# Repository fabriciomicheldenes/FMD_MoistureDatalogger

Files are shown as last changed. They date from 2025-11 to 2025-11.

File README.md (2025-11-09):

# 🌱 Datalogger de Umidade do Solo *FMD_Soil Moisture*

## 📘 Visão Geral

 O **FMD_Soil Moisture** é um sistema autônomo para **monitoramento contínuo de umidade e temperatura do solo**, com armazenamento local e conectividade Wi-Fi e Serial-USB.

Projetado para aplicações agrícolas e experimentais, o sistema registra dados ambientais em longo prazo com alta confiabilidade e baixo custo.

O projeto é baseado em um **Arduino Mega 2560**, que coleta leituras de múltiplos sensores capacitivos de umidade do solo **HW-101 HW**, além de um sensor **DHT22** para temperatura e umidade do ar.

Os dados são registrados em **cartão microSD** e podem ser sincronizados via **módulo ESP-01 (ESP8266)** para monitoramento remoto.

## 🧩 Hardware - Arquitetura Geral

### 🔹 Componentes Principais

| Módulo / Componente | Função | Interface | Observações |
| --- | --- | --- | --- |
| **Arduino Mega 2560** | Unidade de controle principal | – | 16 canais analógicos nativos + expansão SPI |
| **Sensores de Umidade Capacitivos (HW-101 HW V1.2 / V2.0)** | Medição de umidade do solo | Analógica (0–5 V) | 16 sensores diretos + 2 via MCP3008 |
| **MCP3008** | Conversor A/D externo de 8 canais | SPI | Expande entradas |
| **DHT22** | Temperatura e umidade do ar | 1 fio (digital) | Sensor ambiente |
| **ESP-01 (ESP8266)** | Comunicação Wi-Fi | UART | Upload de dados ou configuração remota |
| **RTC DS1307 + Bateria 3 V** | Relógio e calendário | I²C | Mantém data/hora durante desligamento |
| **MicroSD Card (SPI)** | Armazenamento local | SPI | Indicadores de status via LEDs |
| **LEDs de Status (3×)** | Indicação do estado do SDCard | GPIO | - Sem cartão<br>- Falha no cartão<br>- Cartão OK (pisca ao gravar) |

## ⚙️ Recursos Adicionais (não implementados (no firmware) na versão atual)

| Recurso | Componente | Interface | Estado |
| --- | --- | --- | --- |
| Memória EEPROM externa | 24C32WP | I²C | Reservado |
| Display LCD 1602 | HD44780 (modo 4 bits) | GPIO | Reservado |
| Display 5110 | Nokia 5110 | SPI | Reservado |
| Teclado | Teclado matricial 4×4 | GPIO | Reservado |
| Expansão ADC | MCP3008 (canais livres) | SPI | Reservado |

## 🔌 Conectores de Expansão

| Conector | Interface | Descrição |
| --- | --- | --- |
| **Expansão A** | I²C, 1× I/O, 2× PWM | Compatível com sensores e atuadores externos |
| **Expansão B** | SPI, CS, 1× I/O, 1× PWM | Para módulos SPI adicionais |
| **Expansão C** | SPI, CS, 1× I/O, 1× PWM | Similar à Expansão B |
| **Expansão D (Serial)** | TX/RX, 1× I/O, 2× PWM | Conexão de módulos seriais ou periféricos externos |
| **Planejado** | RS-232 e RS-485 | UART + controle de hardware |

## 🧾 Histórico de Versões do Hardware

| Versão | Plataforma | Descrição | Status |
| --- | --- | --- | --- |
| **V0.1** | Proteus (ISIS + ARES) | Primeira versão funcional do circuito e layout | ✅ Testada |
| **V0.2** | KiCad 8 | Novo layout, roteamento otimizado e serigrafia revisada | 🔄 Atual  |

A **versão V0.1**, desenvolvida no *Proteus (ISIS + ARES)*, foi a primeira versão funcional do hardware, mas apresentava algumas limitações de projeto, como trilhas longas e cruzadas, componentes em ambos os lados e uso reduzido de plano de terra, exigindo pequenas correções com jumpers.

A **versão V0.2**, redesenhada no *KiCad 8*, manteve o mesmo circuito eletrônico, mas trouxe um layout mais maduro e eficiente: todos os componentes estão em um único lado, as trilhas são curtas e bem distribuídas, e há ampla costura de planos de terra em ambas as faces, resultando em **melhor imunidade a ruídos** e maior confiabilidade do sistema.

## 💾 Firmware

O firmware foi desenvolvido em **Arduino C++**, com foco em modularidade e confiabilidade para operação contínua.  
Ele realiza:

- Leitura sequencial dos sensores de umidade e do DHT22  
- Registro no **RTC DS1307** para carimbo de data/hora  
- Armazenamento no **microSD (FAT32)**  
- Indicação visual do status via LEDs  
- Envio de dados via **Wi-Fi (ESP-01)**  

### 🔹 Bibliotecas utilizadas

- `DHT.h` – leitura de temperatura/umidade  
- `Wire.h` – comunicação I²C (RTC e EEPROM)  
- `SPI.h` – comunicação SPI (SD e MCP3008)  
- `SD.h` – gerenciamento do cartão microSD  
- `SoftwareSerial.h` – interface serial com ESP-01  

> 🔗 Detalhes do código e pinagem em [`Firmware/README.md`](Firmware/README.md)

---

## 💻 Software de Visualização

O software de visualização foi desenvolvido em **Python/Qt**, permitindo:

- Leitura direta dos arquivos `.CSV` ou `.TXT` do microSD  
- Exibição de gráficos de tendência (umidade x tempo)  
- Exportação dos dados para análise estatística  
- Modo de operação **offline (SD)** e **online (Wi-Fi)**  

> 🔗 Documentação completa em [`Software/README.md`](Software/README.md)

---

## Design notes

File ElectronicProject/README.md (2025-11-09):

# 🌱 Datalogger de Umidade do Solo *FMD_Soil Moisture* – Hardware

## 📘 Visão Geral

 O **FMD_Soil Moisture** é um sistema autônomo para **monitoramento contínuo de umidade e temperatura do solo**, com armazenamento local e conectividade Wi-Fi e Serial-USB.

Projetado para aplicações agrícolas e experimentais, o sistema registra dados ambientais em longo prazo com alta confiabilidade e baixo custo.

O projeto é baseado em um **Arduino Mega 2560**, que coleta leituras de múltiplos sensores capacitivos de umidade do solo **HW-101 HW**, além de um sensor **DHT22** para temperatura e umidade do ar.

Os dados são registrados em **cartão microSD** e podem ser sincronizados via **módulo ESP-01 (ESP8266)** para monitoramento remoto.

## 🧩 Arquitetura Geral

### 🔹 Componentes Principais

| Módulo / Componente | Função | Interface | Observações |
| --- | --- | --- | --- |
| **Arduino Mega 2560** | Unidade de controle principal | – | 16 canais analógicos nativos + expansão SPI |
| **Sensores de Umidade Capacitivos (HW-101 HW V1.2 / V2.0)** | Medição de umidade do solo | Analógica (0–5 V) | 16 sensores diretos + 2 via MCP3008 |
| **MCP3008** | Conversor A/D externo de 8 canais | SPI | Expande entradas |
| **DHT22** | Temperatura e umidade do ar | 1 fio (digital) | Sensor ambiente |
| **ESP-01 (ESP8266)** | Comunicação Wi-Fi | UART | Upload de dados ou configuração remota |
| **RTC DS1307 + Bateria 3 V** | Relógio e calendário | I²C | Mantém data/hora durante desligamento |
| **MicroSD Card (SPI)** | Armazenamento local | SPI | Indicadores de status via LEDs |
| **LEDs de Status (3×)** | Indicação do estado do SDCard | GPIO | - Sem cartão<br>- Falha no cartão<br>- Cartão OK (pisca ao gravar) |

## ⚙️ Recursos Adicionais (não implementados (no firmware) na versão atual)

| Recurso | Componente | Interface | Estado |
| --- | --- | --- | --- |
| Memória EEPROM externa | 24C32WP | I²C | Reservado |
| Display LCD 1602 | HD44780 (modo 4 bits) | GPIO | Reservado |
| Display 5110 | Nokia 5110 | SPI | Reservado |
| Teclado | Teclado matricial 4×4 | GPIO | Reservado |
| Expansão ADC | MCP3008 (canais livres) | SPI | Reservado |

## 🔌 Conectores de Expansão

| Conector | Interface | Descrição |
| --- | --- | --- |
| **Expansão A** | I²C, 1× I/O, 2× PWM | Compatível com sensores e atuadores externos |
| **Expansão B** | SPI, CS, 1× I/O, 1× PWM | Para módulos SPI adicionais |
| **Expansão C** | SPI, CS, 1× I/O, 1× PWM | Similar à Expansão B |
| **Expansão D (Serial)** | TX/RX, 1× I/O, 2× PWM | Conexão de módulos seriais ou periféricos externos |
| **Planejado** | RS-232 e RS-485 | UART + controle de hardware |

## 🧾 Histórico de Versões do Hardware

| Versão | Plataforma | Descrição | Status |
| --- | --- | --- | --- |
| **V0.1** | Proteus (ISIS + ARES) | Primeira versão funcional do circuito e layout | ✅ Testada |
| **V0.2** | KiCad 8 | Novo layout, roteamento otimizado e serigrafia revisada | 🔄 Atual  |

As **Figuras 1 e 2** apresentam a **versão V0.1** da placa, elaborada utilizando o *Proteus* (ISIS + ARES).  
Embora plenamente funcional, essa versão apresentou algumas limitações construtivas, como **trilhas incompletas que precisaram ser interligadas externamente por jumpers**, um **layout ainda imaturo** com **componentes montados em ambos os lados da placa** e **trilhas longas que se cruzam**, resultando em **pouca área disponível para o plano de terra**.  
Esses aspectos podem ser observados nas **Figuras 3 e 4**, que mostram os lados **superior** e **inferior** da placa.

<figure>
  <p align="center">
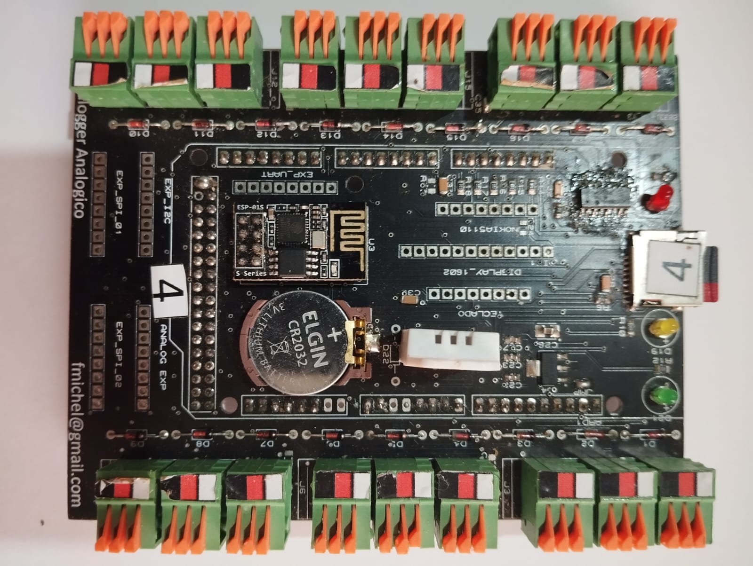
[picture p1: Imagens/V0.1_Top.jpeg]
Figura 1 – Placa V0.1 vista de cima
    
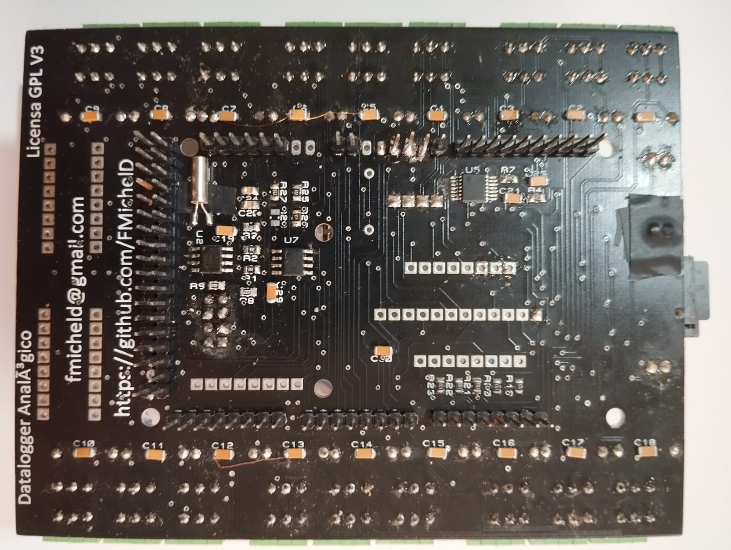
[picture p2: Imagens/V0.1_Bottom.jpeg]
Figura 2 – Placa V0.1 vista de baixo
    
  </p>
  <figcaption align="center"><b>Figura 1</b>: Placa V0.1 vista de cima.  <b> Figura 2</b>: – Placa V0.1 vista de baixo.</figcaption>
</figure>

<figure>
  <p align="center">
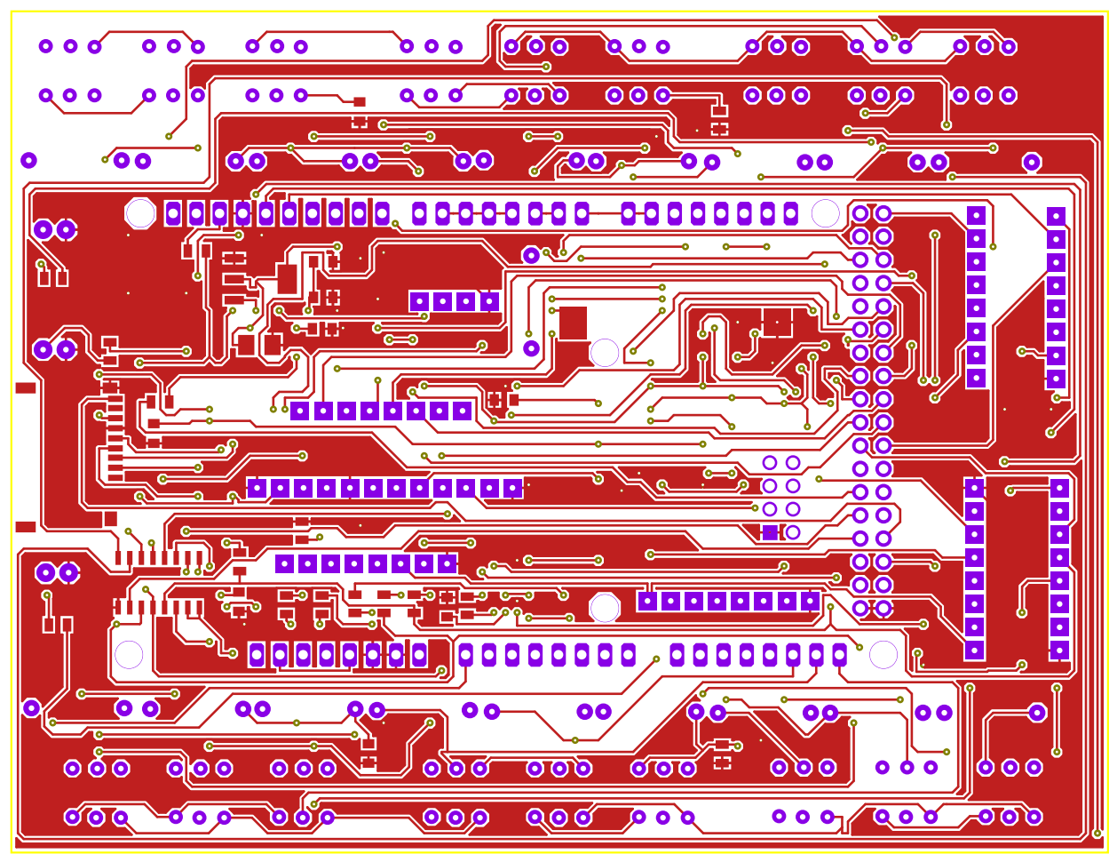
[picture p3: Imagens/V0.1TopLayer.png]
Figura 3 – Placa V0.1 Top layer
    
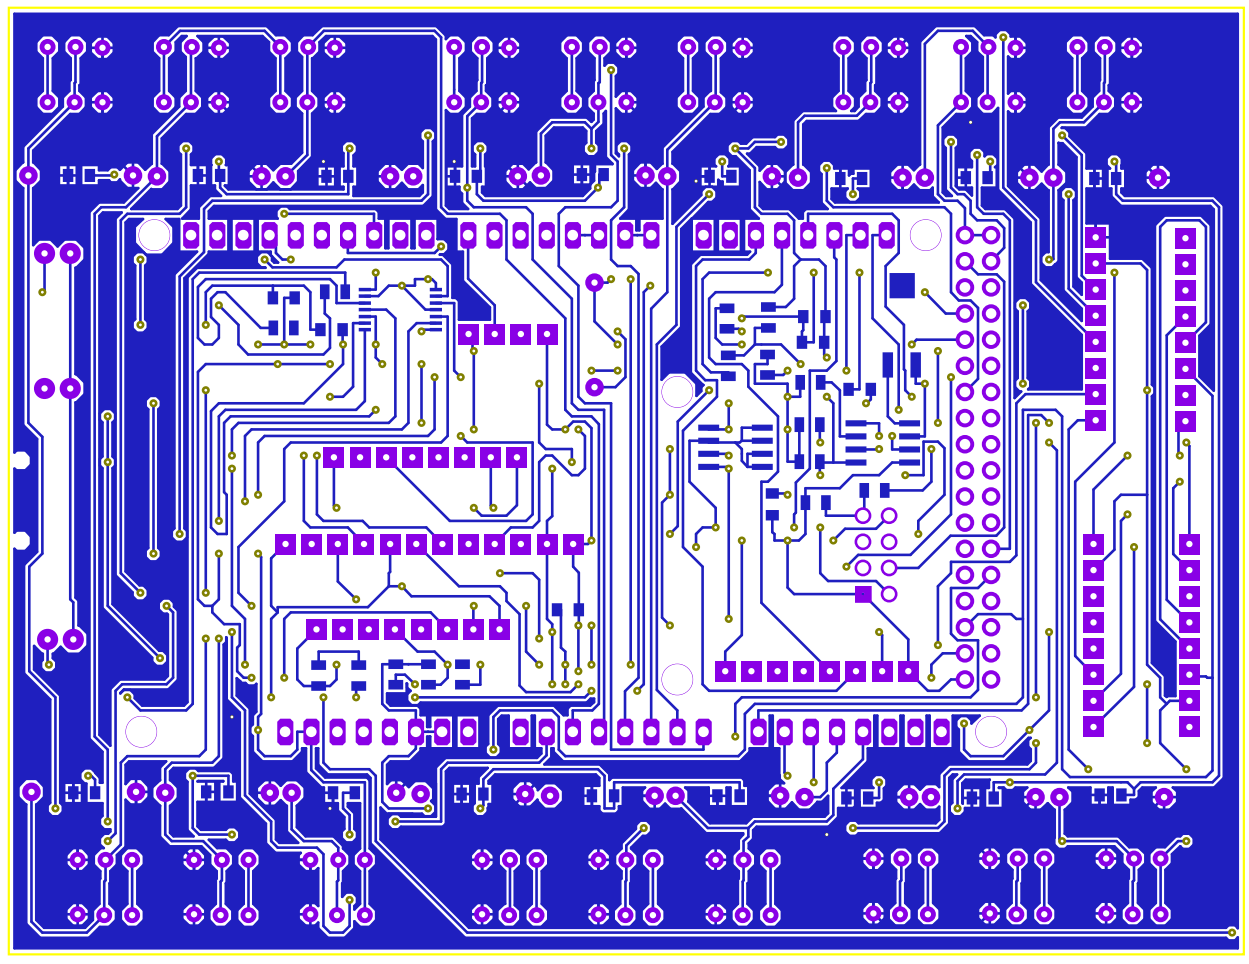
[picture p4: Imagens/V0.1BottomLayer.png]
Figura 4 – Bottom layer
    
  </p>
  <figcaption align="center"><b>Figura 3</b>: Placa V0.1 Top layer.  <b> Figura 4</b>: – Placa V0.1 Bottom layer.</figcaption>
</figure>>

A **versão V0.2**, desenvolvida no **KiCad**, manteve o mesmo circuito eletrônico da versão anterior, porém recebeu um **layout totalmente refeito**, com foco em otimização e robustez.  
Como ilustrado nas **Figuras 5 e 6**, o novo modelo 3D demonstra um **posicionamento mais racional dos componentes**, concentrados **em um único lado da placa**, com **trilhas mais curtas e diretas** e **ampla área para planos de terra em ambas as faces**.  
As **Figuras 7 e 8** evidenciam também a **costura entre planos de terra**, que contribui para **melhorar a imunidade a ruídos** e **reduzir interferências eletromagnéticas (EMI)**, tornando o hardware mais confiável para uso em ambientes agrícolas sujeitos a variações de umidade e ruído elétrico.

<figure>
  <p align="center">
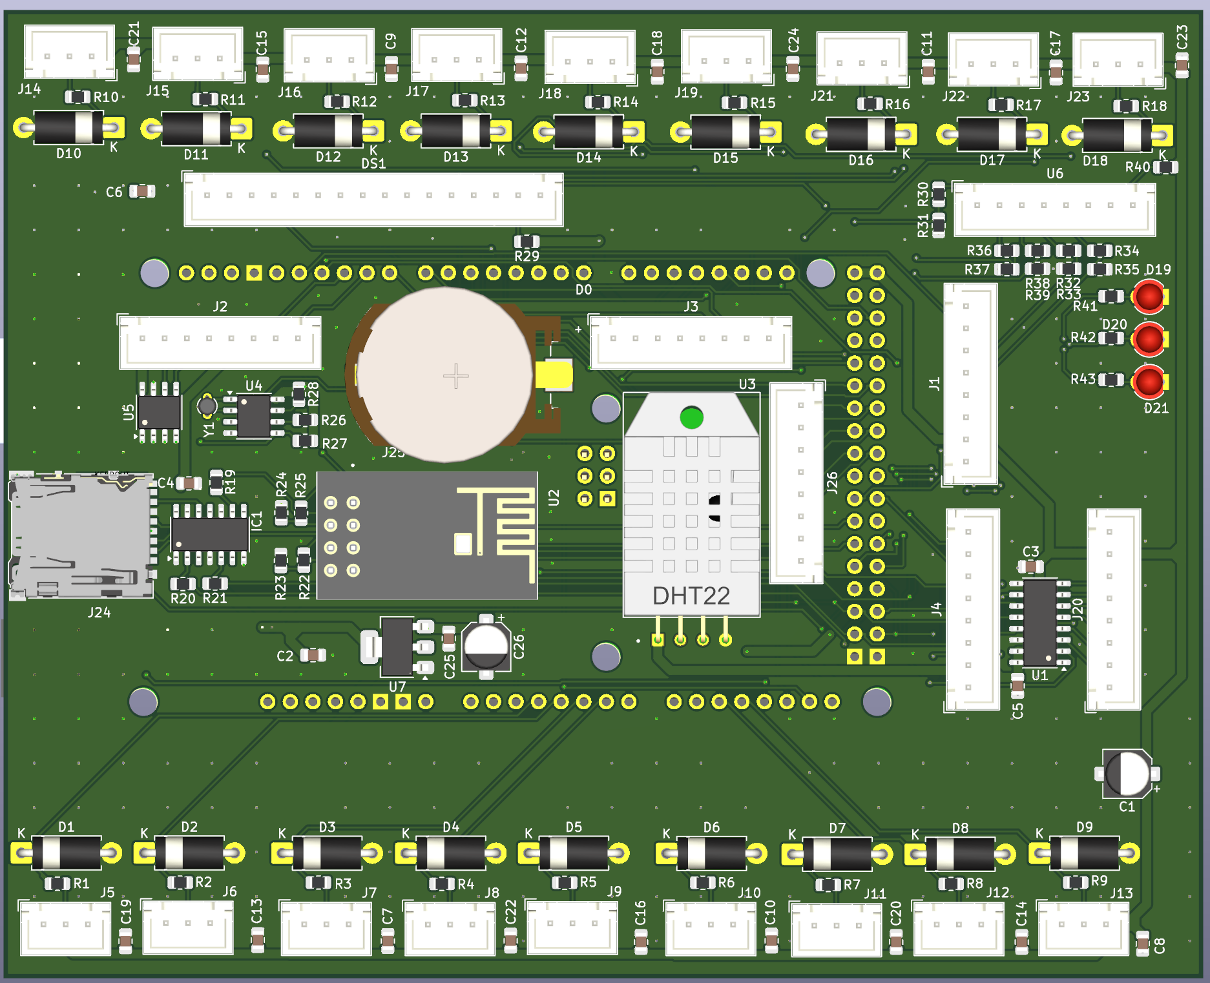
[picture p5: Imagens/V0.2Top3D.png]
Figura 5 – Placa V0.2 vista de cima modelo 3D
    
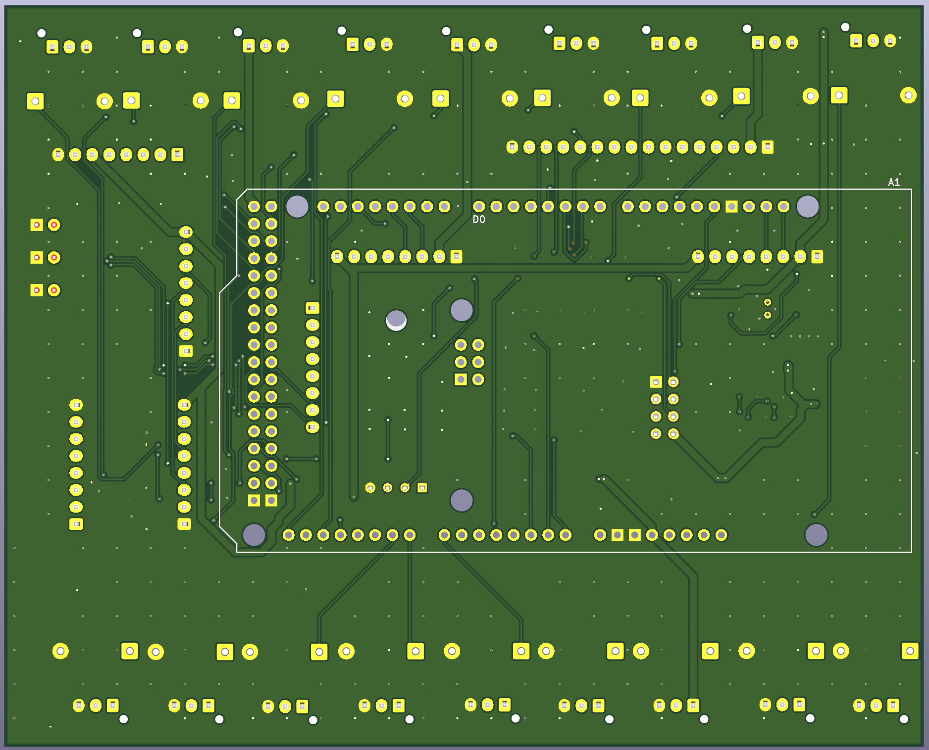
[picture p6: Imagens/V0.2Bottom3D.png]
Figura 6 – Placa V0.2 vista de baixo modelo 3D
    
  </p>
  <figcaption align="center"><b>Figura 5</b>: Placa V0.2 vista de cima, modelo 3D.  <b> Figura 6</b>: – Placa V0.2 vista de baixo, modelo 3D.</figcaption>
</figure>

<figure>
  <p align="center">
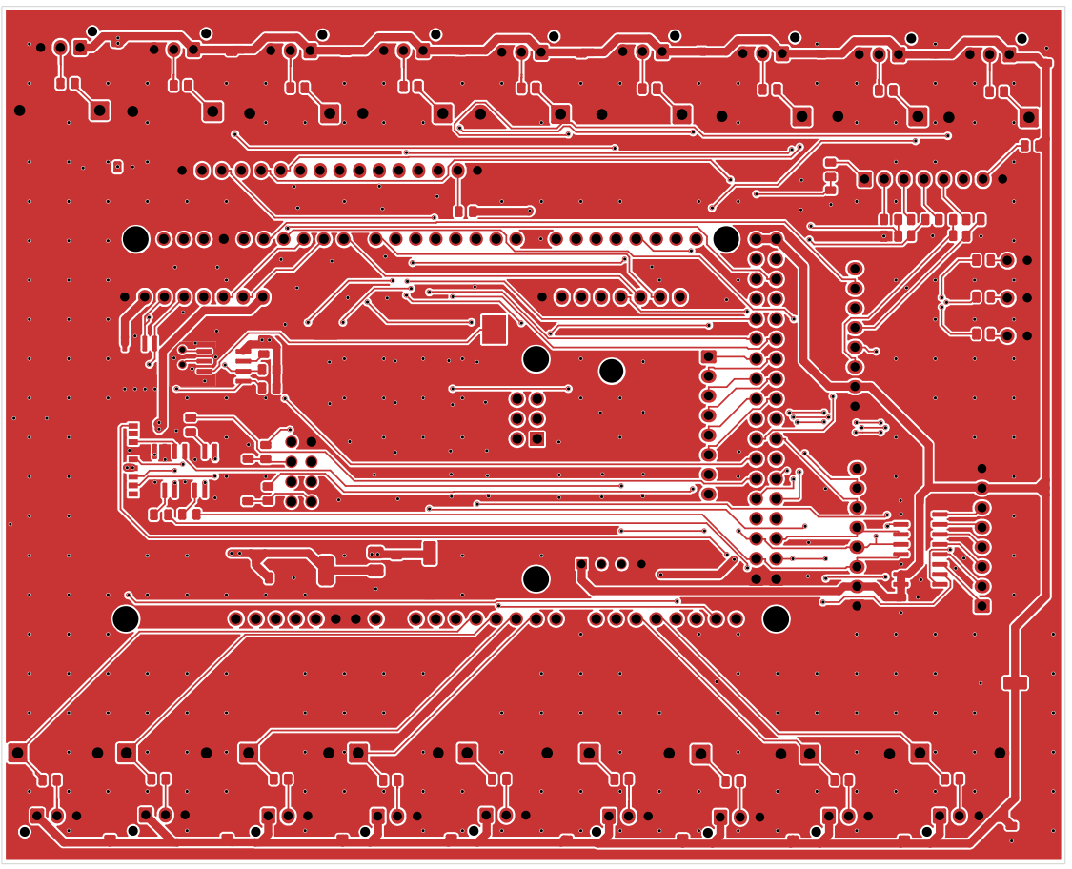
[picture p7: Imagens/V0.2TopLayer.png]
Figura 7 – Placa V0.2 Top layer
    
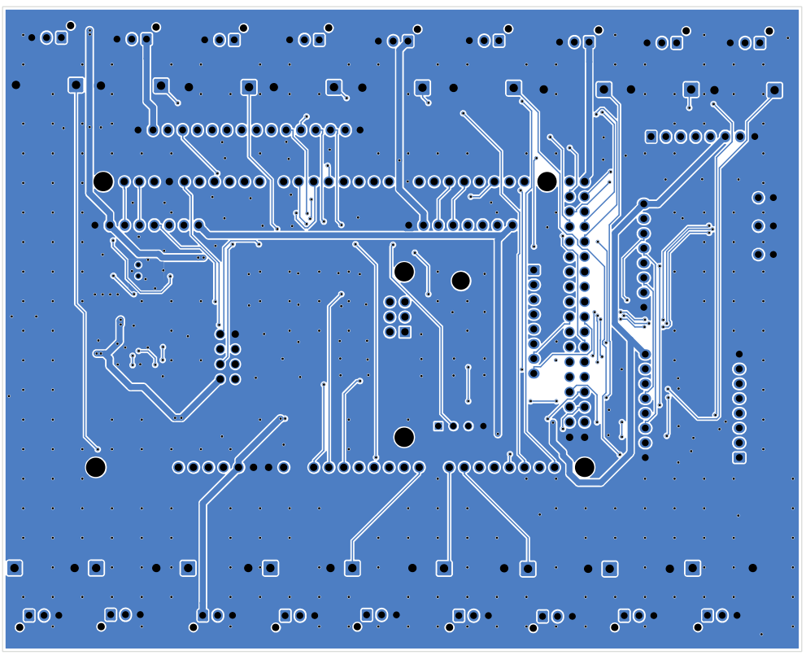
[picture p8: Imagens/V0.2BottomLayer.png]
Figura 8 – Placa V0.2 Bottom layer
    
  </p>
  <figcaption align="center"><b>Figura 7</b>: Placa V0.2 Top layer.  <b> Figura 8</b>: – Placa V0.2 Bottom layer.</figcaption>
</figure>>

## 🧮 Especificações Técnicas

- **Alimentação:** 7 – 12 V DC
- **Consumo típico:** ~200 mA (sem Wi-Fi ativo)
- **Número total de canais de umidade:** 18
- **Resolução ADC (interna):** 10 bits
- **Resolução ADC (externa):** 10 bits (MCP3008)
- **Período de amostragem:** configurável (ex.: 5 s a 10 min)
- **Armazenamento:** microSD FAT32 (até 32 GB)
- **Conectividade:** Wi-Fi (ESP-01), Serial USB

## 🧰 Próximas Melhorias

- Implementação do barramento **RS-485** para rede de sensores.
- Inclusão de **display LCD/Nokia** para feedback local.
- Sistema de **menus via teclado matricial**.
- Adição de **EEPROM 24C32WP** para parâmetros persistentes.

## 📁 Estrutura de Pastas (Hardware)

## 📜 Licença

Este projeto é distribuído sob a licença **MIT**, permitindo uso, modificação e distribuição com atribuição ao autor.

---

**Autor:** Fabrício Michel Denes  
**Repositório:** [github.com/fabriciomicheldenes/FMD_MoistureDatalogger](https://github.com/fabriciomicheldenes/FMD_MoistureDatalogger)

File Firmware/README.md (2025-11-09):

# 🌱 FMD Moisture Datalogger Firmware
Sistema embarcado de registro de umidade do solo desenvolvido por Fabrício Michel Denes.

---

## ⚙️ Ambiente de Desenvolvimento

### 🔧 Requisitos principais
| Componente | Descrição |
|---|---|
| **Compilador AVR-GCC** | Toolchain oficial da Microchip. Caminho padrão: `E:\AVR\avr8-gnu-toolchain-win32_x86_64` |
| **CMake** | ≥ 3.28 com suporte ao generator *Ninja* |
| **Ninja Build** | Sistema de build rápido e compatível com CMake |
| **Arduino Core (AVR)** | Instalado via Arduino IDE (> 2.0). Caminho padrão: `%USERPROFILE%\AppData\Local\Arduino15\packages\arduino\hardware\avr\1.8.6` |
| **AVRDUDE** | Para upload do firmware (`avrdude.exe` no toolchain ou Arduino IDE) |

---

## 🧩 Estrutura de Pastas
```
Firmware/
├── CMakeLists.txt
├── cmake/
│ └── avr-toolchain.cmake
├── src/
│ ├── app.cpp
│ ├── system.cpp
│ └── …
├── include/
│ ├── HardwarePins.h
│ ├── DHT22.h
│ ├── RtcTimer.h
│ └── …
├── build.bat ← script interativo para build + upload
└── build/ ← artefatos gerados (.elf /.hex /.bin)
``` 

---

## 🚀 Compilação e Upload

### 🧰 Opção 1 – Via VS Code + CMake Tools
1. Abrir a pasta `Firmware/` no VS Code.  
2. Selecionar o generator **Ninja**.  
3. Executar **CMake Configure** → **CMake Build**.  
4. O arquivo `.elf` será gerado em `build/`.  
5. Rodar `ninja upload` para gravar no Arduino.

### 🖥️ Opção 2 – Via Terminal
```bash
cd Firmware/build
cmake .. -G "Ninja"
ninja
ninja upload

💡 Opção 3 – Via Script build.bat (interativo)
> build.bat
==========================================
Portas seriais disponíveis:
Port Name
---- ----
COM1  Porta de comunicação (COM1)
COM4  USB-SERIAL CH340 (COM4)
==========================================

Digite a porta (ex: COM4):

O script compila automaticamente e chama ninja upload, enviando o firmware para o Arduino Mega 2560.

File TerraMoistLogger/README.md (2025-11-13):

# 🌱  TerraMoistLogger

## TODO: terminar de editar este README

Sistema de Monitoramento de Umidade do Solo – GUI para até 4 TerraMoistSense

O TerraMoistLogger é uma interface gráfica desenvolvida em Qt para monitorar até 4 dispositivos TerraMoistSense, cada um equipado com:

16 sensores analógicos nativos (ATmega2560)

2 sensores externos via MCP3008 (SPI)

**🔢 Total de sensores por dispositivo: 18**

**🔢 Total suportado pela GUI: 4 × 18 = 72 sensores**

O sistema foi criado para ser portátil, leve e compatível com hardware antigo — rodando atualmente em Qt 5.5 - 32 bits, porém planejado para migrar para Qt 6.x, mantendo compatibilidade com versões antigas para uso em netbooks e PCs modestos.

## 📌 Funcionalidades Principais
**-✔️ Autodetecção de dispositivos via USB/Serial**

A GUI detecta automaticamente conexão e desconexão de dispositivos

Atualização de portas monitorada a cada 1 segundo
(implementado em MainWindow::scanSerialPorts() – 

mainwindow

)

**-✔️ Gerenciamento automático das interfaces (ConsoleManager)**

Cada dispositivo é gerenciado por um ConsoleManager, criado dinamicamente:

Instância de QSerialPort

Conexão automática

Leitura de dados em tempo real

Configuração automática do intervalo de registro

(Classes referentes: consolemanager.h, console.h – )

**-✔️ Leitura e exibição de dados de até 72 sensores simultaneamente**

O TerraMoistSense envia dados no formato:

```
YYYY/MM/DD;HH:MM:SS;valorCH1;...;valorCH18;umidade;temperatura;ID_dispositivos;SalvoOUNãonoCartão
````

## A GUI:

organiza em 4 consoles independentes

salva logs (quando ativado)

permite visualizar, limpar e configurar os dispositivos

**-✔️ Configuração de intervalo de registro**

Controlada via combo box (registerFrequency no MainWindow – 

mainwindow

):

5 segundos

10 segundos

1 minuto

5 minutos

15 minutos

30 minutos

60 minutos

120 minutos

**-✔️ Totalmente compatível com hardware antigo**

Qt 5.5 – 32bit usado por compatibilidade com Acer One / Netbooks antigos

Código preparado para migração gradual para Qt 6 (Windows/Linux)

🏗️ Arquitetura Geral da Aplicação
Estrutura principal do projeto
TerraMoistLogger/
│   CMakeLists.txt
│   main.cpp
│   mainwindow.h / .cpp / .ui
│   consolemanager.h / .cpp
│   console.h / .cpp / .ui
│   settingsdialog.h / .cpp / .ui
│   QSerialPortInfoOperatores.h / .cpp
│   images/
│       *.png
│   app.ico
│   TerraMoistLogger.pro
│   TerraMoistLogger.qrc

Diagrama de classes simplificado
MainWindow
 ├── QList<QSerialPortInfo>
 ├── QList<QSerialPort*>
 ├── QList<ConsoleManager*>
 ├── registerFrequency (QComboBox)
 └── scanSerialPorts()  ----> detecta conexão/desconexão

ConsoleManager
 ├── QSerialPort*
 ├── Console*
 ├── Intervalo de registro
 └── Envio/Recepção de dados

Console
 ├── Widget de exibição de dados
 ├── Botões de comando
 └── Sinais Qt para comunicação

🔌 Comunicação Serial
🔍 Autodetecção

O método scanSerialPorts() compara portas atuais com as previamente listadas e, se houver alteração, reconstrói toda a interface automaticamente:

mainwindow

🔧 Configuração automática

O método autoConnect() gera dinamicamente até 4 ConsoleManager, um para cada TerraMoistSense conectado:

mainwindow

📡 Compatibilidade com TerraMoistSense (Firmware)

A GUI foi projetada para trabalhar com as funcionalidades atuais do firmware:

RTC DS1307

DHT22

ADC nativo (ATmega2560 – 16 canais)

ADC MCP3008 (SPI – 2 canais)

SDCard como armazenamento interno

Indicação por LED de presença/erro/atividade

Envio de logs padronizados

Planejamento para futuras versões

Integração com ESP-01 (upload sem fio)

Upload MQTT ou HTTP

Status remoto do dispositivo

Configuração de datalogger via GUI

📦 Build
Requisitos atuais

Qt 5.5 (32 bits)

CMake 3.16+

MinGW 4.9 ou MSVC 2015 (dependendo da build)

Make (Windows)
mkdir build
cd build
cmake ..
cmake --build . --config Release

Executável gerado
build/TerraMoistLogger.exe

🗺️ Roadmap
✔️ Versão atual

GUI funcional com suporte automático para 4 dispositivos

Logging e leitura em tempo real

Compatível com equipamentos antigos

Suporte completo ao protocolo atual do TerraMoistSense

🚧 Versões futuras

Migração para Qt 6

Novo design responsivo

Dashboards com gráficos

Conexão com ESP-01

Banco de dados local SQLite

Exportação para CSV/XLSX

Modo “Live Dashboard” para agrônomos e laboratórios

📚 Licença

O TerraMoistLogger segue a mesma licença do QtSerialPort utilizado internamente, conforme apresentado nos cabeçalhos originais do Qt — como no arquivo mainwindow.cpp:

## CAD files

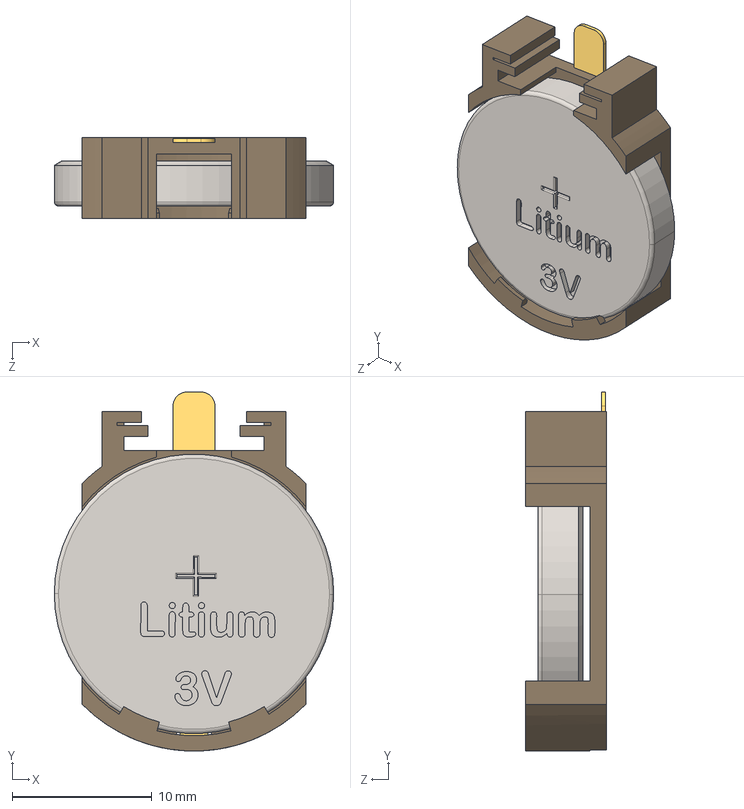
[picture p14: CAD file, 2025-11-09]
ElectronicProject/V0.2-Kicad/3D Models/Battery Keeper 2032 PART.STEP
20.0 x 25.7 x 5.80 mm

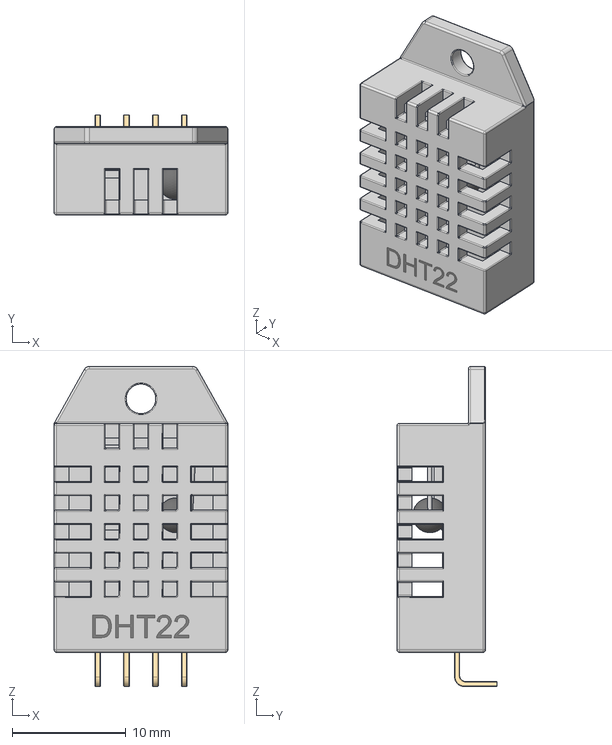
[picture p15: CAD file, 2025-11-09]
ElectronicProject/V0.2-Kicad/3D Models/Version 1.1 - DHT22 Temperatursensor.step
15.3 x 8.80 x 28.2 mm

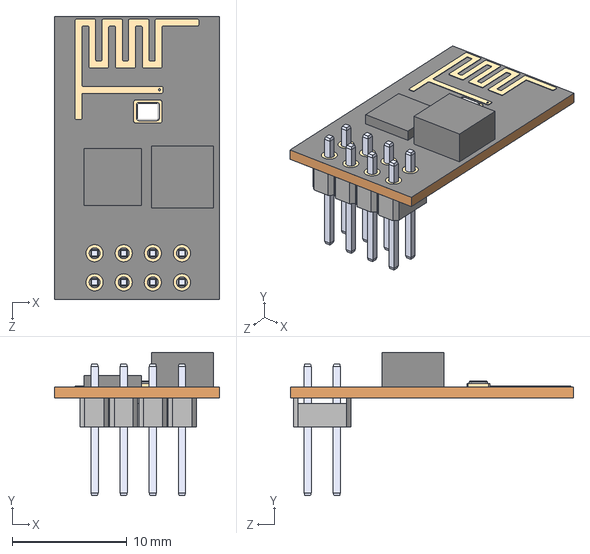
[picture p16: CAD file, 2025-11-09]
ElectronicProject/V0.2-Kicad/3D Models/ESP-01.STEP
14.4 x 12.5 x 24.7 mm

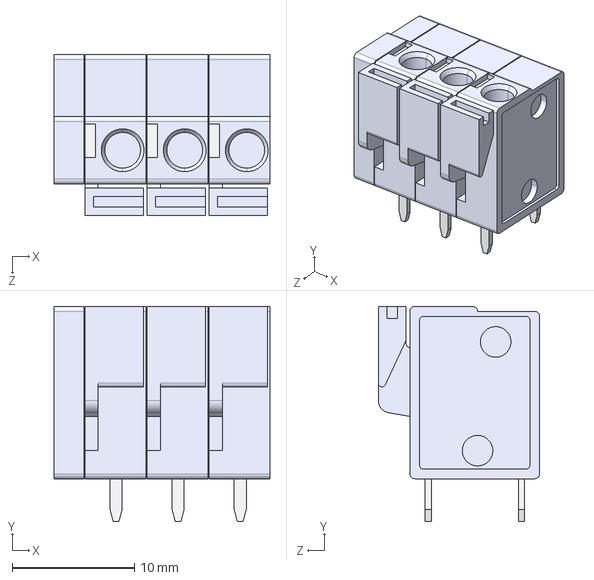
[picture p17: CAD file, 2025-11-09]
ElectronicProject/V0.2-Kicad/3D Models/DG142V-3-5.08.STEP
17.7 x 17.6 x 13.2 mm

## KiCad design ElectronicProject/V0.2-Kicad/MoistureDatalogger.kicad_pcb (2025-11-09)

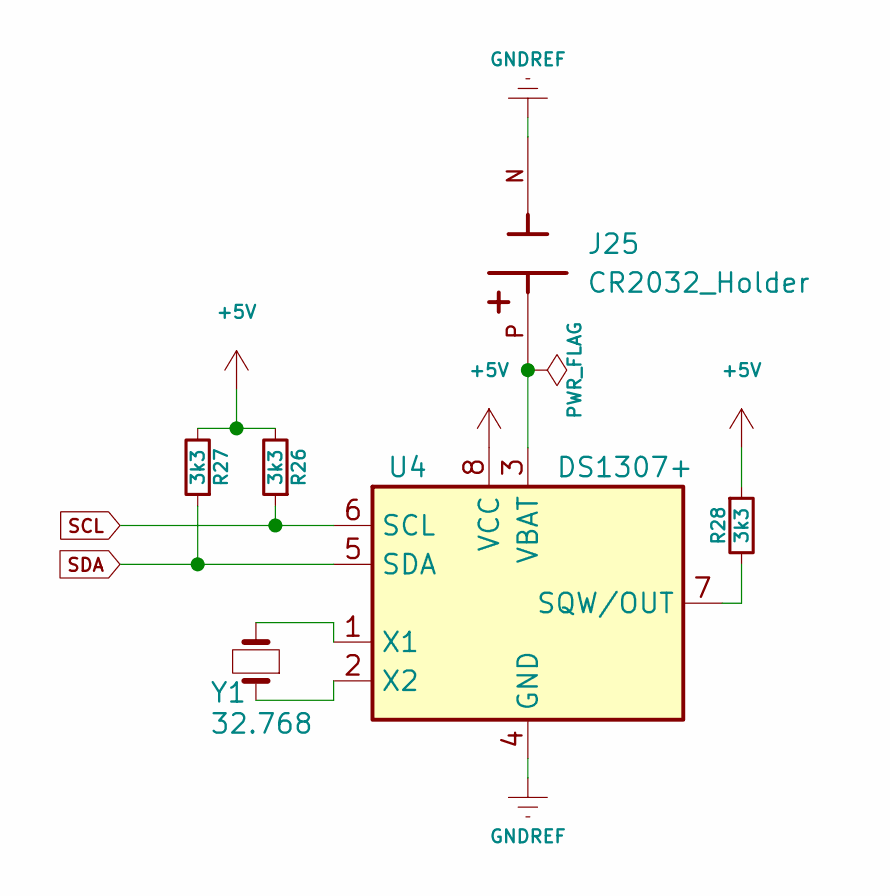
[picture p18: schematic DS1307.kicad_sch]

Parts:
J25: CR2032_Holder; HARWIN_S8421-45R
R26, R27, R28: 3k3; R_0805_2012Metric
U4: DS1307+; SOIC-8_3.9x4.9mm_P1.27mm
Y1: 32.768; Crystal_DS26_D2.0mm_L6.0mm_Vertical

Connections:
+5V: R26.2, R27.2, R28.1, U4.8 (VCC); also elsewhere on the board
GNDREF: J25.N, U4.4 (GND); also elsewhere on the board
unnamed: R28.2, U4.7 (SQW/OUT)
unnamed: J25.P, U4.3 (VBAT)
unnamed: U4.1 (X1), Y1.2
unnamed: U4.2 (X2), Y1.1
SCL: R26.1, U4.6 (SCL); also elsewhere on the board
SDA: R27.1, U4.5 (SDA); also elsewhere on the board

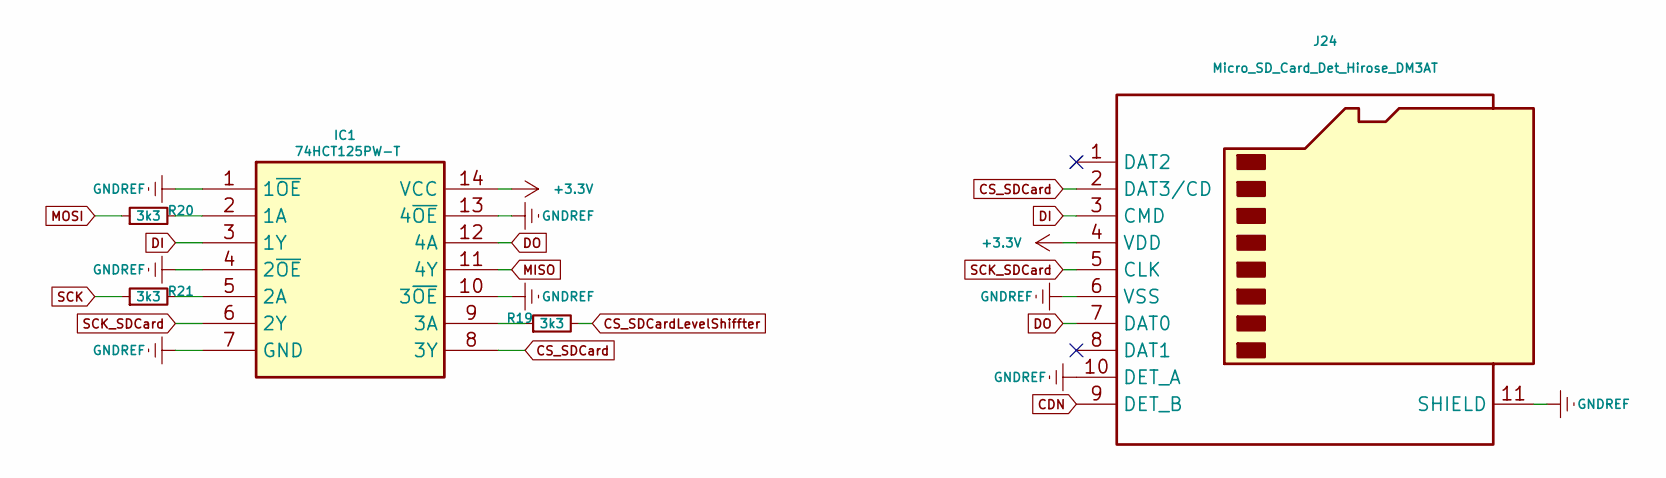
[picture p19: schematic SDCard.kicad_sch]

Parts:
IC1: 74HCT125PW-T; SOIC-14_3.9x8.7mm_P1.27mm; Manufacturer_Part_Number 74HCT125PW-T
J24: Micro_SD_Card_Det_Hirose_DM3AT; microSD_HC_Hirose_DM3AT-SF-PEJM5
R19, R20, R21: 3k3; R_0805_2012Metric

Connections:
+3.3V: IC1.14 (VCC), J24.4 (VDD); also elsewhere on the board
CDN: J24.9 (DET_B); also elsewhere on the board
CS_SDCard: IC1.8 (3Y), J24.2 (DAT3/CD)
CS_SDCardLevelShiffter: R19.2; also elsewhere on the board
DI: IC1.3 (1Y), J24.3 (CMD)
DO: IC1.12 (4A), J24.7 (DAT0)
GNDREF: IC1.1 (1~OE), IC1.4 (2~OE), IC1.7 (GND), IC1.10 (3~OE), IC1.13 (4~OE), J24.6 (VSS), J24.10 (DET_A), J24.11 (SHIELD); also elsewhere on the board
MISO: IC1.11 (4Y); also elsewhere on the board
MOSI: R20.1; also elsewhere on the board
unnamed: IC1.2 (1A), R20.2
unnamed: IC1.5 (2A), R21.2
unnamed: IC1.9 (3A), R19.1
SCK: R21.1; also elsewhere on the board
SCK_SDCard: IC1.6 (2Y), J24.5 (CLK)

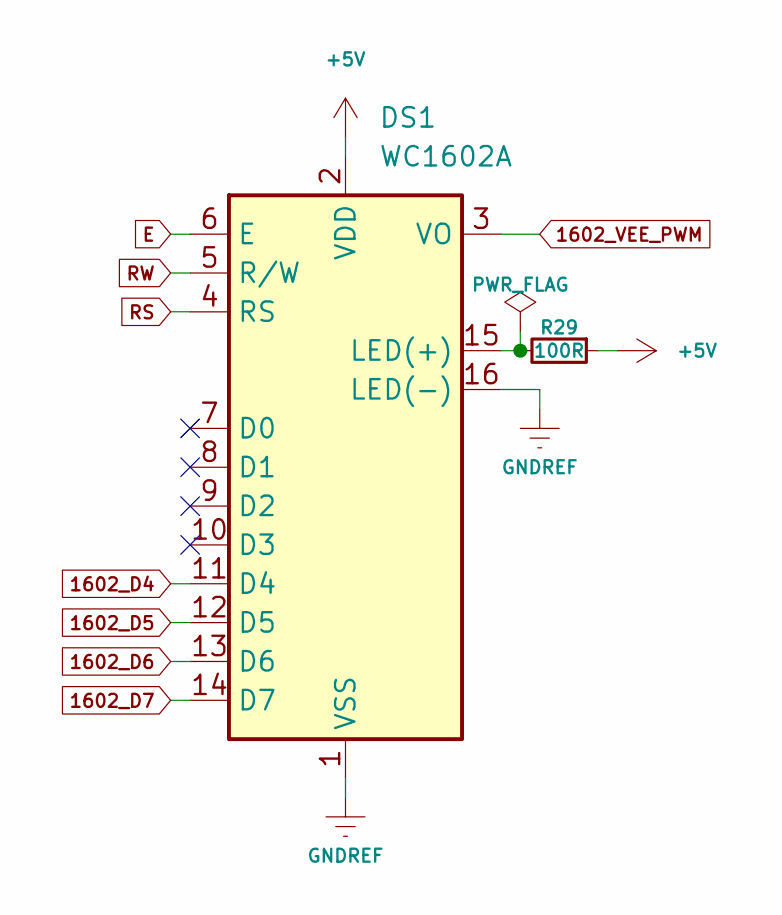
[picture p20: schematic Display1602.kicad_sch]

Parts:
DS1: WC1602A; JST_XH_B16B-XH-A_1x16_P2.50mm_Vertical
R29: 100R; R_0805_2012Metric

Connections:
1602_D4: DS1.11 (D4); also elsewhere on the board
1602_D5: DS1.12 (D5); also elsewhere on the board
1602_D6: DS1.13 (D6); also elsewhere on the board
1602_D7: DS1.14 (D7); also elsewhere on the board
1602_VEE_PWM: DS1.3 (VO); also elsewhere on the board
+5V: DS1.2 (VDD), R29.1; also elsewhere on the board
E: DS1.6 (E); also elsewhere on the board
GNDREF: DS1.1 (VSS), DS1.16 (LED(-)); also elsewhere on the board
unnamed: DS1.15 (LED(+)), R29.2
RS: DS1.4 (RS); also elsewhere on the board
RW: DS1.5 (R/W); also elsewhere on the board

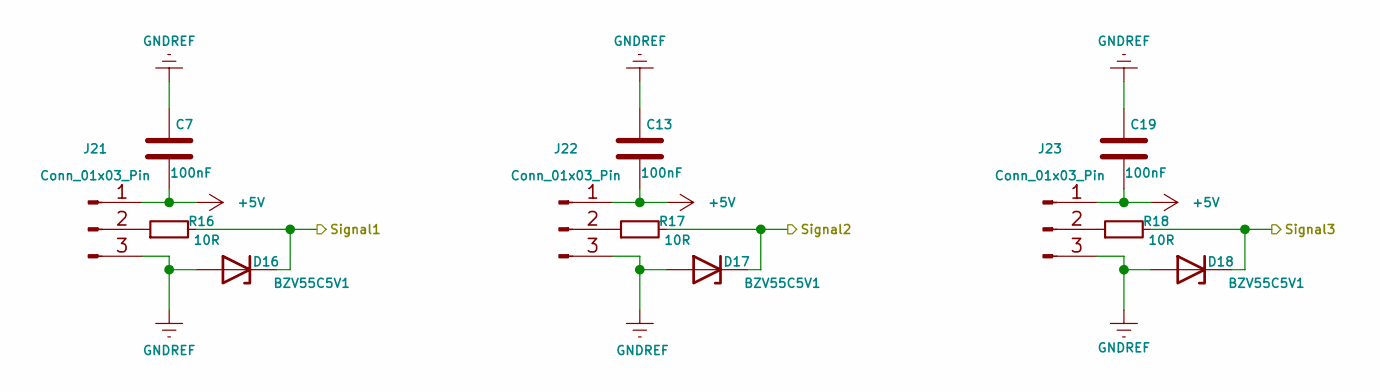
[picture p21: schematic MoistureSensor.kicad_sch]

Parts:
C7, C13, C19: 100nF; C_0805_2012Metric
D16, D17, D18: BZV55C5V1; D_DO-15_P10.16mm_Horizontal
J21, J22, J23: Conn_01x03_Pin; JST_XH_B3B-XH-AM_1x03_P2.50mm_Vertical
R16, R17, R18: 10R; R_0805_2012Metric

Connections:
+5V: C7.2, C13.2, C19.2, J21.1, J22.1, J23.1; also elsewhere on the board
/Microcontroller2560/A0: D16.1 (K), R16.2; also elsewhere on the board
/Microcontroller2560/A1: D17.1 (K), R17.2; also elsewhere on the board
/Microcontroller2560/A2: D18.1 (K), R18.2; also elsewhere on the board
GNDREF: C7.1, C13.1, C19.1, D16.2 (A), D17.2 (A), D18.2 (A), J21.3, J22.3, J23.3; also elsewhere on the board
unnamed: J21.2, R16.1
unnamed: J22.2, R17.1
unnamed: J23.2, R18.1

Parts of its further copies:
C8, C9, C10, C11, C12, C14, C15, C16, C17, C18, C20, C21, C22, C23, C24: 100nF; C_0805_2012Metric
D1, D2, D3, D4, D5, D6, D7, D8, D9, D10, D11, D12, D13, D14, D15: BZV55C5V1; D_DO-15_P10.16mm_Horizontal
J5, J6, J7, J8, J9, J10, J11, J12, J13, J14, J15, J16, J17, J18, J19: Conn_01x03_Pin; JST_XH_B3B-XH-AM_1x03_P2.50mm_Vertical
R1, R2, R3, R4, R5, R6, R7, R8, R9, R10, R11, R12, R13, R14, R15: 10R; R_0805_2012Metric

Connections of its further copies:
+5V: C8.2, C9.2, C10.2, C11.2, C12.2, C14.2, C15.2, C16.2, C17.2, C18.2, C20.2, C21.2, C22.2, C23.2, C24.2, J5.1, J6.1, J7.1, J8.1, J9.1, J10.1, J11.1, J12.1, J13.1, J14.1, J15.1, J16.1, J17.1, J18.1, J19.1; also elsewhere on the board
/MCP3008/A16: D14.1 (K), R14.2; also elsewhere on the board
/MCP3008/A17: D15.1 (K), R15.2; also elsewhere on the board
/Microcontroller2560/A3: D1.1 (K), R1.2; also elsewhere on the board
/Microcontroller2560/A4: D2.1 (K), R2.2; also elsewhere on the board
/Microcontroller2560/A5: D3.1 (K), R3.2; also elsewhere on the board
/Microcontroller2560/A6: D4.1 (K), R4.2; also elsewhere on the board
/Microcontroller2560/A7: D5.1 (K), R5.2; also elsewhere on the board
/Microcontroller2560/A8: D6.1 (K), R6.2; also elsewhere on the board
/Microcontroller2560/A9: D7.1 (K), R7.2; also elsewhere on the board
/Microcontroller2560/A10: D8.1 (K), R8.2; also elsewhere on the board
/Microcontroller2560/A11: D9.1 (K), R9.2; also elsewhere on the board
/Microcontroller2560/A12: D10.1 (K), R10.2; also elsewhere on the board
/Microcontroller2560/A13: D11.1 (K), R11.2; also elsewhere on the board
/Microcontroller2560/A14: D12.1 (K), R12.2; also elsewhere on the board
/Microcontroller2560/A15: D13.1 (K), R13.2; also elsewhere on the board
GNDREF: C8.1, C9.1, C10.1, C11.1, C12.1, C14.1, C15.1, C16.1, C17.1, C18.1, C20.1, C21.1, C22.1, C23.1, C24.1, D1.2 (A), D2.2 (A), D3.2 (A), D4.2 (A), D5.2 (A), D6.2 (A), D7.2 (A), D8.2 (A), D9.2 (A), D10.2 (A), D11.2 (A), D12.2 (A), D13.2 (A), D14.2 (A), D15.2 (A), J5.3, J6.3, J7.3, J8.3, J9.3, J10.3, J11.3, J12.3, J13.3, J14.3, J15.3, J16.3, J17.3, J18.3, J19.3; also elsewhere on the board
unnamed: J5.2, R1.1
unnamed: J6.2, R2.1
unnamed: J7.2, R3.1
unnamed: J8.2, R4.1
unnamed: J9.2, R5.1
unnamed: J10.2, R6.1
unnamed: J11.2, R7.1
unnamed: J12.2, R8.1
unnamed: J13.2, R9.1
unnamed: J14.2, R10.1
unnamed: J15.2, R11.1
unnamed: J16.2, R12.1
unnamed: J17.2, R13.1
unnamed: J18.2, R14.1
unnamed: J19.2, R15.1

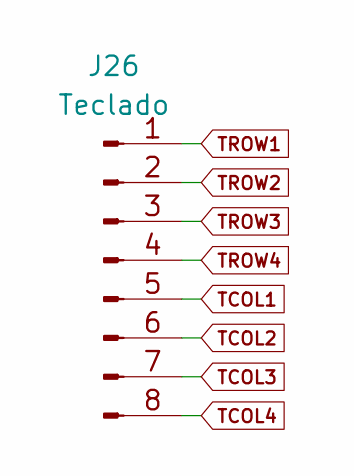
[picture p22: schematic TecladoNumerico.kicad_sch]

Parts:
J26: Teclado; JST_XH_B8B-XH-A_1x08_P2.50mm_Vertical

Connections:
TCOL1: J26.5; also elsewhere on the board
TCOL2: J26.6; also elsewhere on the board
TCOL3: J26.7; also elsewhere on the board
TCOL4: J26.8; also elsewhere on the board
TROW1: J26.1; also elsewhere on the board
TROW2: J26.2; also elsewhere on the board
TROW3: J26.3; also elsewhere on the board
TROW4: J26.4; also elsewhere on the board

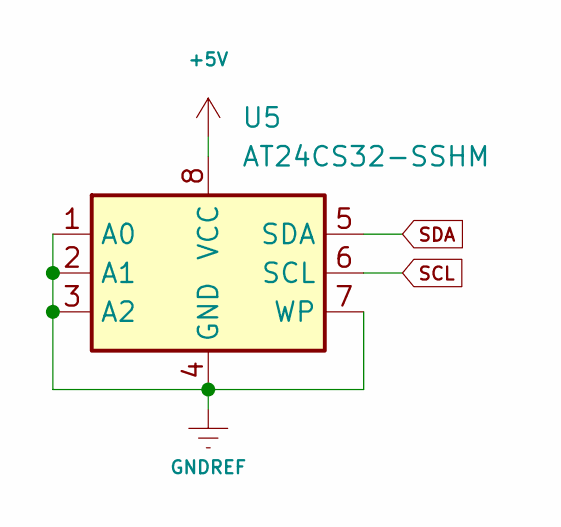
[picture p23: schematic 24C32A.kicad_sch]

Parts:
U5: AT24CS32-SSHM; SOIC-8_3.9x4.9mm_P1.27mm

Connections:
+5V: U5.8 (VCC); also elsewhere on the board
GNDREF: U5.1 (A0), U5.2 (A1), U5.3 (A2), U5.4 (GND), U5.7 (WP); also elsewhere on the board
SCL: U5.6 (SCL); also elsewhere on the board
SDA: U5.5 (SDA); also elsewhere on the board

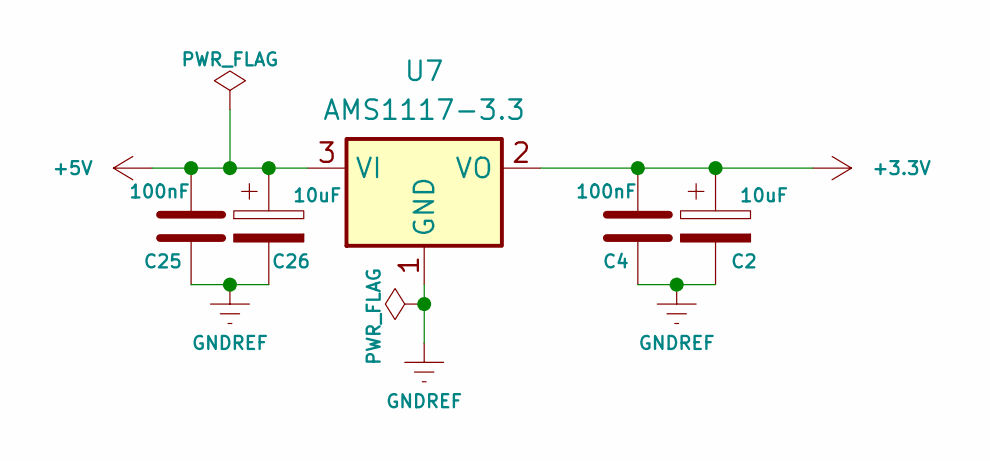
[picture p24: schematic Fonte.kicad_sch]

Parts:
C2: 10uF; C_0805_2012Metric
C4, C25: 100nF; C_0805_2012Metric
C26: 10uF; CP_Elec_5x5.8
U7: AMS1117-3.3; SOT-223-3_TabPin2

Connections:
+3.3V: C2.1, C4.2, U7.2 (VO); also elsewhere on the board
+5V: C25.2, C26.1, U7.3 (VI); also elsewhere on the board
GNDREF: C2.2, C4.1, C25.1, C26.2, U7.1 (GND); also elsewhere on the board

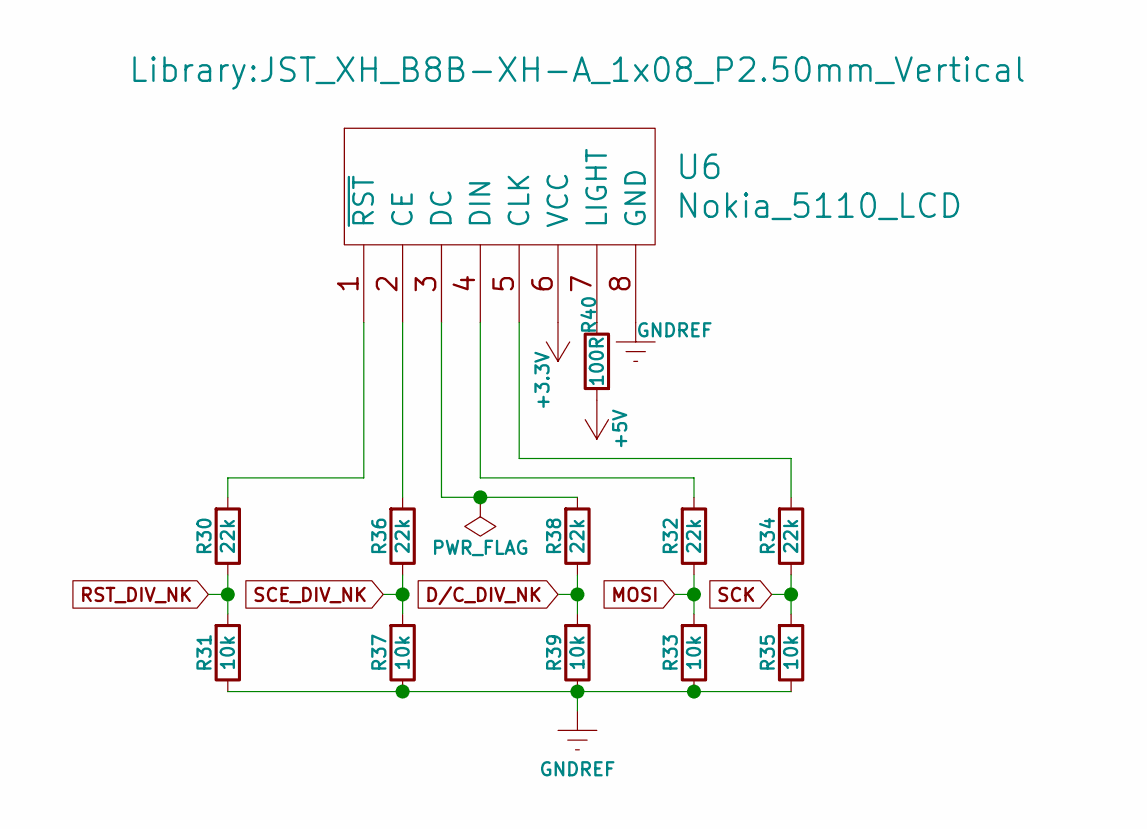
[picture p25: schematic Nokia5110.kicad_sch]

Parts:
R30, R32, R34, R36, R38: 22k; R_0805_2012Metric
R31, R33, R35, R37, R39: 10k; R_0805_2012Metric
R40: 100R; R_0805_2012Metric
U6: Nokia_5110_LCD; JST_XH_B8B-XH-A_1x08_P2.50mm_Vertical

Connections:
+3.3V: U6.6 (VCC); also elsewhere on the board
+5V: R40.1; also elsewhere on the board
D/C_DIV_NK: R38.2, R39.1; also elsewhere on the board
GNDREF: R31.2, R33.2, R35.2, R37.2, R39.2, U6.8 (GND); also elsewhere on the board
MOSI: R32.2, R33.1; also elsewhere on the board
unnamed: R36.1, U6.2 (CE)
unnamed: R34.1, U6.5 (CLK)
unnamed: R38.1, U6.3 (DC)
unnamed: R32.1, U6.4 (DIN)
unnamed: R40.2, U6.7 (LIGHT)
unnamed: R30.1, U6.1 (~RST)
RST_DIV_NK: R30.2, R31.1; also elsewhere on the board
SCE_DIV_NK: R36.2, R37.1; also elsewhere on the board
SCK: R34.2, R35.1; also elsewhere on the board

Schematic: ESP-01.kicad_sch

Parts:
R22, R25: 2k2; R_0805_2012Metric
R23, R24: 1k; R_0805_2012Metric
U2: ESP-01; MODULE_ESP-01; PARTREV 1.0

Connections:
+3.3V: U2.5 (VCC); also elsewhere on the board
CS_ESP: R25.2; also elsewhere on the board
ESP_~RST: U2.6 (~RST); also elsewhere on the board
GNDREF: R23.1, R24.1, U2.1 (GND); also elsewhere on the board
unnamed: R24.2, R25.1, U2.7 (CH_PD)
unnamed: R22.1, R23.2, U2.4 (RXD)
RX_ARD: U2.8 (TXD); also elsewhere on the board
TX_ARD: R22.2; also elsewhere on the board

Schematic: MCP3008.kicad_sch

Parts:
C5: 100nF; C_0805_2012Metric
C6: 10uF; C_0805_2012Metric
J20: ANALOG_EXP; JST_XH_B8B-XH-A_1x08_P2.50mm_Vertical
U1: MCP3008; SOIC-16_3.9x9.9mm_P1.27mm

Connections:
+5V: C5.2, C6.1, J20.7, U1.15 (Vref), U1.16 (Vdd); also elsewhere on the board
/MCP3008/A16: U1.1 (CH0); also elsewhere on the board
/MCP3008/A17: U1.2 (CH1); also elsewhere on the board
CS_MCP3008: U1.10 (~CS/SHDN); also elsewhere on the board
GNDREF: C5.1, C6.2, J20.8, U1.9 (DGND), U1.14 (AGND); also elsewhere on the board
MISO: U1.12 (Dout); also elsewhere on the board
MOSI: U1.11 (Din); also elsewhere on the board
unnamed: J20.1, U1.3 (CH2)
unnamed: J20.2, U1.4 (CH3)
unnamed: J20.3, U1.5 (CH4)
unnamed: J20.4, U1.6 (CH5)
unnamed: J20.5, U1.7 (CH6)
unnamed: J20.6, U1.8 (CH7)
SCK: U1.13 (CLK); also elsewhere on the board

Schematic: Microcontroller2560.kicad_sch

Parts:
A1: Arduino_Mega2560_R3_Shield
C1: 10uF; CP_Elec_5x5.8
C3: 100nF; C_0805_2012Metric
D19: LED_RED; LED_D3.0mm
D20: LED_YELLOW; LED_D3.0mm
D21: LED_GREEN; LED_D3.0mm
J1: EXP_SPI_01; JST_XH_B8B-XH-A_1x08_P2.50mm_Vertical
J2: EXP_I2C; JST_XH_B8B-XH-A_1x08_P2.50mm_Vertical
J3: EXP_UART; JST_XH_B8B-XH-A_1x08_P2.50mm_Vertical
J4: EXP_SPI_02; JST_XH_B8B-XH-A_1x08_P2.50mm_Vertical
R41, R42, R43: 100R; R_0805_2012Metric

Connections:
1602_D4: A1.D28; also elsewhere on the board
1602_D5: A1.D29; also elsewhere on the board
1602_D6: A1.D30; also elsewhere on the board
1602_D7: A1.D31; also elsewhere on the board
1602_VEE_PWM: A1.D4; also elsewhere on the board
+3.3V: J1.8, J2.8, J3.8, J4.8; also elsewhere on the board
+5V: A1.5V1 (5V), A1.5V3 (5V), A1.5V4 (5V), C1.1, C3.2, J1.2, J2.2, J3.2, J4.2; also elsewhere on the board
/Microcontroller2560/A0: A1.A0; also elsewhere on the board
/Microcontroller2560/A1: A1.A1; also elsewhere on the board
/Microcontroller2560/A2: A1.A2; also elsewhere on the board
/Microcontroller2560/A3: A1.A3; also elsewhere on the board
/Microcontroller2560/A4: A1.A4; also elsewhere on the board
/Microcontroller2560/A5: A1.A5; also elsewhere on the board
/Microcontroller2560/A6: A1.A6; also elsewhere on the board
/Microcontroller2560/A7: A1.A7; also elsewhere on the board
/Microcontroller2560/A8: A1.A8; also elsewhere on the board
/Microcontroller2560/A9: A1.A9; also elsewhere on the board
/Microcontroller2560/A10: A1.A10; also elsewhere on the board
/Microcontroller2560/A11: A1.A11; also elsewhere on the board
/Microcontroller2560/A12: A1.A12; also elsewhere on the board
/Microcontroller2560/A13: A1.A13; also elsewhere on the board
/Microcontroller2560/A14: A1.A14; also elsewhere on the board
/Microcontroller2560/A15: A1.A15; also elsewhere on the board
CDN: A1.D49; also elsewhere on the board
CS_ESP: A1.D13; also elsewhere on the board
CS_MCP3008: A1.D48, A1.D53 (D53_CS); also elsewhere on the board
CS_SDCardLevelShiffter: A1.D44; also elsewhere on the board
DHT_DATA: A1.D6; also elsewhere on the board
D/C_DIV_NK: A1.D24; also elsewhere on the board
E: A1.D27; also elsewhere on the board
ESP_~RST: A1.D5; also elsewhere on the board
EXP_D0: A1.D40, J1.6
EXP_D1: A1.D41, J4.6
EXP_D2: A1.D42, J2.5
EXP_D3: A1.D43, J3.5
EXP_PWM_01: A1.D12, J1.7
EXP_PWM_02: A1.D11, J4.7
EXP_PWM_03: A1.D10, J2.6
EXP_PWM_04: A1.D9, J2.7
EXP_PWM_05: A1.D8, J3.6
EXP_PWM_06: A1.D7, J3.7
GNDREF: A1.GND1 (GND), A1.GND2 (GND), A1.GND3 (GND), A1.GND5 (GND), A1.GND6 (GND), C1.2, C3.1, D19.1 (K), D20.1 (K), D21.1 (K), J1.1, J2.1, J3.1, J4.1; also elsewhere on the board
MISO: A1.D50 (D50_MISO), J1.4, J4.4; also elsewhere on the board
MOSI: A1.D51 (D51_MOSI), J1.3, J4.5; also elsewhere on the board
unnamed: D19.2 (A), R41.2
unnamed: D20.2 (A), R42.2
unnamed: D21.2 (A), R43.2
RS: A1.D25; also elsewhere on the board
RST_DIV_NK: A1.D22; also elsewhere on the board
RW: A1.D26; also elsewhere on the board
RX2_ARD: A1.D17 (D17/RX2), J3.4
RX_ARD: A1.D19 (D19/RX1); also elsewhere on the board
SCE_DIV_NK: A1.D23; also elsewhere on the board
SCK: A1.D52 (D52_SCK), J1.5, J4.3; also elsewhere on the board
SCL: A1.SCL, J2.3; also elsewhere on the board
SDA: A1.SDA, J2.4; also elsewhere on the board
SDCARD_FAIL: A1.D45, R41.1
SDCARD_NONE: A1.D46, R42.1
SDCARD_OK: A1.D47, R43.1
TCOL1: A1.D36; also elsewhere on the board
TCOL2: A1.D37; also elsewhere on the board
TCOL3: A1.D38; also elsewhere on the board
TCOL4: A1.D39; also elsewhere on the board
TROW1: A1.D32; also elsewhere on the board
TROW2: A1.D33; also elsewhere on the board
TROW3: A1.D34; also elsewhere on the board
TROW4: A1.D35; also elsewhere on the board
TX2_ARD: A1.D16 (D16/TX2), J3.3
TX_ARD: A1.D18 (D18/TX1); also elsewhere on the board

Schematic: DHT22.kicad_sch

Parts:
U3: DHT22; XDCR_DHT22

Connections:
+5V: U3.1 (VDD); also elsewhere on the board
DHT_DATA: U3.2 (DATA); also elsewhere on the board
GNDREF: U3.4 (GND); also elsewhere on the board

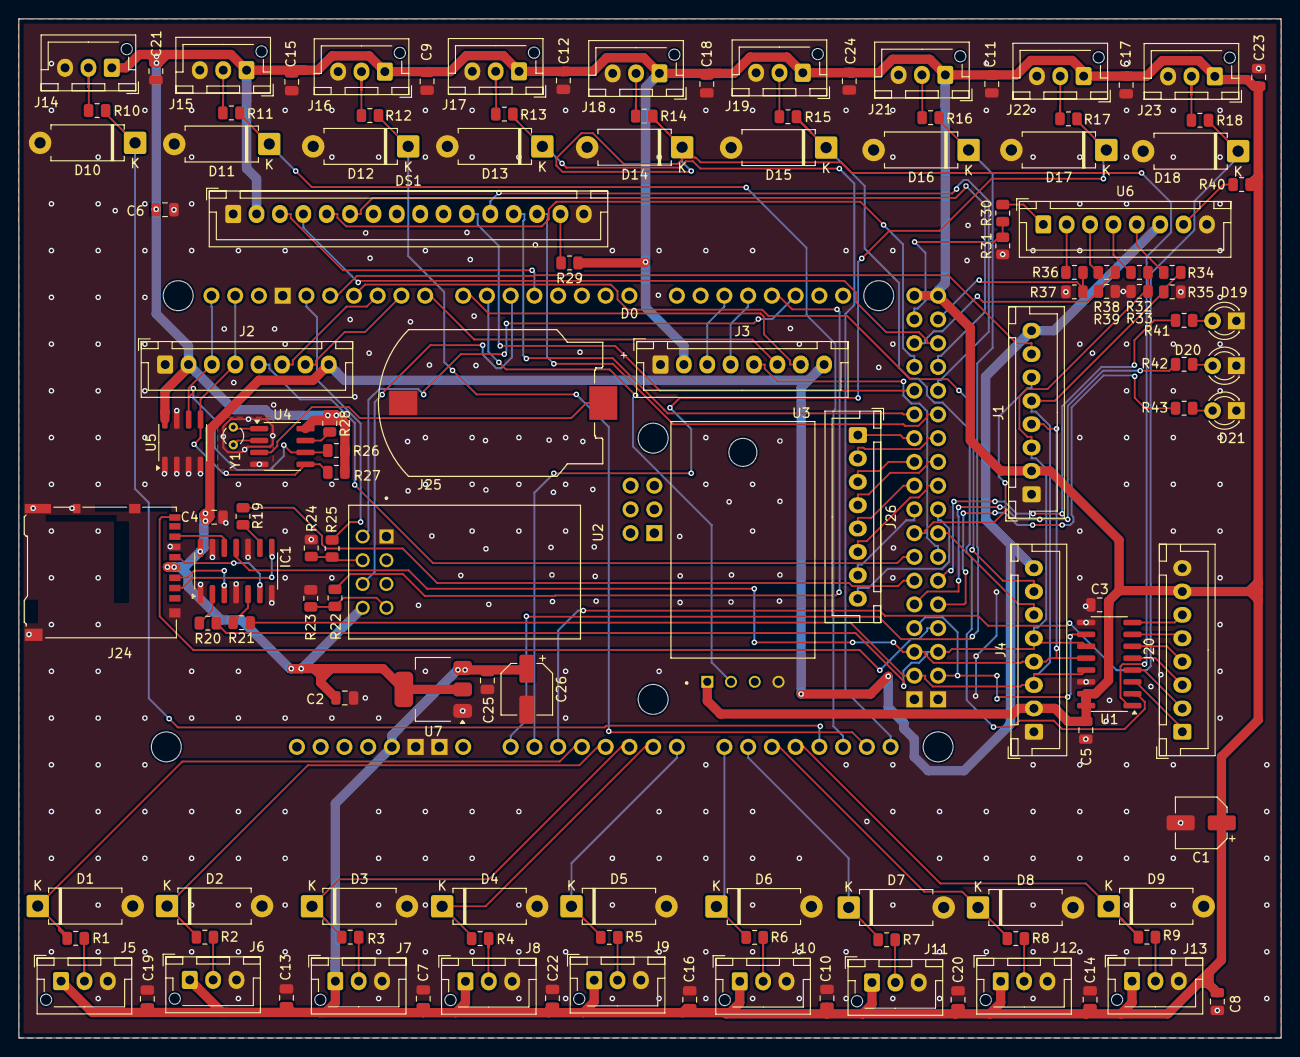
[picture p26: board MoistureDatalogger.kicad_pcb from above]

Board: 2 copper layers, 135.0 x 109.0 mm, 127 parts (0 on the bottom side), 115 nets.

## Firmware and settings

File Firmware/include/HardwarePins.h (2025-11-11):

/**
 * * @file HardwarePins.h
 * TODO: @brief <TODO: Descrição breve do propósito do arquivo>
 *
 * @details
 * Parte integrante do projeto Moisture Datalogger.
 * Contém a implementação das rotinas de controle e comunicação do sistema,
 * incluindo o parser de comandos, interface serial e mediador de módulos.
 *
 * @author
 *   Fabrício Michel Denes (FMD)
 * @date
 *   2025
 *
 * @copyright
 *   © 2025 Fabrício Michel Denes. Todos os direitos reservados.
 *
 * @license
 *   Este código é distribuído sob a licença MIT.
 *   Consulte o arquivo LICENSE ou visite:
 *   https://opensource.org/licenses/MIT
 *
 * @version
 * * v0.2.x  - Em desenvolvimento
 */

#pragma once
#include <Arduino.h>

/**
 * @brief Define os pinos de hardware utilizados pelo sistema de aquisição.
 *
 * Mantém todos os pinos organizados em uma única estrutura, facilitando
 * ajustes de hardware e manutenção do código.
 *
 * Compatível com Arduino Mega 2560.
 */
class HardwarePins {
   public:
    // --------------------------------------------------
    // 🧩 ADCs
    // --------------------------------------------------
    static constexpr uint8_t CS_MCP3008 = 48;  // Chip Select do ADC externo (SPI)
    static constexpr uint8_t ADC0_PIN = A0;    // ADC interno canal 0
    static constexpr uint8_t ADC1_PIN = A1;    // ADC interno canal 1
    static constexpr uint8_t ADC2_PIN = A2;
    static constexpr uint8_t ADC3_PIN = A3;
    static constexpr uint8_t ADC4_PIN = A4;
    static constexpr uint8_t ADC5_PIN = A5;
    static constexpr uint8_t ADC6_PIN = A6;
    static constexpr uint8_t ADC7_PIN = A7;
    static constexpr uint8_t ADC8_PIN = A8;
    static constexpr uint8_t ADC9_PIN = A9;
    static constexpr uint8_t ADC10_PIN = A10;
    static constexpr uint8_t ADC11_PIN = A11;
    static constexpr uint8_t ADC12_PIN = A12;
    static constexpr uint8_t ADC13_PIN = A13;
    static constexpr uint8_t ADC14_PIN = A14;
    static constexpr uint8_t ADC15_PIN = A15;

    // --------------------------------------------------
    // 🌡️ Sensores de ambiente
    // --------------------------------------------------
    // Sensor de temperatura/umidade DHT22
    static constexpr uint8_t DHT_PIN = 7;

    // --------------------------------------------------
    // ⏰ RTC DS1307 (I2C)
    // --------------------------------------------------
    static constexpr uint8_t I2C_SDA = 20;  // SDA I2C
    static constexpr uint8_t I2C_SCL = 21;  // SCL I2C

    // --------------------------------------------------
    // 💾 SD Card (SPI)
    // --------------------------------------------------
    static constexpr uint8_t CS_SDCARD = 44;  // Chip Select do módulo SD
    static constexpr uint8_t NoCard = 47;
    static constexpr uint8_t CardFail = 46;
    static constexpr uint8_t CardOK = 45;
    static constexpr uint8_t MissingSdCard = 49;

    // --------------------------------------------------
    // 📡 Módulo Wi-Fi ESP-01 (UART)
    // --------------------------------------------------
    // static constexpr uint8_t ESP01_TX    = 18;  // TX → RX do Mega
    // static constexpr uint8_t ESP01_RX    = 19;  // RX → TX do Mega
    // static constexpr uint8_t ESP01_RST   = 8;   // Reset do ESP-01
    // static constexpr uint8_t ESP01_EN    = 9;   // Enable (CH_PD)
    struct ESP01Pins {
        uint8_t tx;
        uint8_t rx;
        uint8_t rst;
        uint8_t en;
    };

    static constexpr ESP01Pins ESP01{
        18,  // TX → RX do Mega
        19,  // RX → TX do Mega
        8,   // Reset
        9    // Enable (CH_PD)
    };

    // --------------------------------------------------
    // 💡 LEDs e debug
    // --------------------------------------------------
    static constexpr uint8_t LED_STATUS = 13;  // LED onboard

    HardwarePins() = default;
};

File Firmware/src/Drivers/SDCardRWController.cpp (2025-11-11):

/**
 * * @file SDCardRWController.cpp
 * TODO: @brief <TODO: Descrição breve do propósito do arquivo>
 *
 * @details
 * Parte integrante do projeto Moisture Datalogger.
 * Contém a implementação das rotinas de controle e comunicação do sistema,
 * incluindo o parser de comandos, interface serial e mediador de módulos.
 *
 * @author
 *   Fabrício Michel Denes (FMD)
 * @date
 *   2025
 *
 * @copyright
 *   © 2025 Fabrício Michel Denes. Todos os direitos reservados.
 *
 * @license
 *   Este código é distribuído sob a licença MIT.
 *   Consulte o arquivo LICENSE ou visite:
 *   https://opensource.org/licenses/MIT
 *
 * @version
 * * v0.2.x  - Em desenvolvimento
 */

#include "Drivers/SDCardRWController.h"
#include "HardwarePins.h"

// volatile bool ledState = false;
// volatile unsigned long lastToggle = 0;

// Variáveis estáticas para ISR
volatile bool ledBlinkEnabled = false;
volatile bool ledState = false;
volatile unsigned long blinkStopTime = 0;

bool SDCardRWController::begin() {
    pinMode(HardwarePins::NoCard, OUTPUT);
    pinMode(HardwarePins::CardFail, OUTPUT);
    pinMode(HardwarePins::CardOK, OUTPUT);
    setupLedBlinkTimer();
    pinMode(HardwarePins::MissingSdCard, INPUT_PULLUP);

    updateLedStatus(false, false, false);

    if (!isCardInserted()) {
        Serial.println(F("⚠️ Nenhum cartão detectado."));
        updateLedStatus(true, false, false);  // vermelho aceso
        initialized = false;
        lastErrorMsg = F("No card");
        return false;
    }

    if (!SD.begin(cs)) {
        Serial.println(F("❌ Falha ao inicializar SDCard."));
        updateLedStatus(false, true, false);  // amarelo aceso
        initialized = false;
        lastErrorMsg = F("Init fail");
        return false;
    }

    Serial.println(F("🟢 SDCard inicializado com sucesso."));
    updateLedStatus(false, false, true);
    initialized = true;
    lastErrorMsg = F("OK");
    return true;
}

void SDCardRWController::printStatus() const {
    Serial.print(F("[SDCard] Status: "));
    Serial.println(initialized ? F("OK") : F("FALHA"));
}

bool SDCardRWController::appendCSV(const String& dataLine, bool verbose) {
    if (!initialized) {
        if (verbose)
            Serial.println(F("⚠️ SDCard não inicializado."));
        lastErrorMsg = F("not_ready");
        return false;
    }

    File file = SD.open(filename, FILE_WRITE);
    if (!file) {
        lastErrorMsg = F("open_fail");
        if (verbose)
            Serial.println(F("❌ Falha ao abrir arquivo para escrita."));
        return false;
    }

    bool success = file.println(dataLine);
    file.close();

    if (success) {
        lastErrorMsg = F("OK");
        return true;
    } else {
        lastErrorMsg = F("write_fail");
        if (verbose)
            Serial.println(F("❌ Falha ao escrever no SDCard."));
        return false;
    }
}

bool SDCardRWController::isCardInserted() const {
    return digitalRead(HardwarePins::MissingSdCard) == LOW;  // LOW = presente
}

void SDCardRWController::updateLedStatus(bool noCard, bool fail, bool ok) {
    digitalWrite(HardwarePins::NoCard, noCard);
    digitalWrite(HardwarePins::CardFail, fail);
    digitalWrite(HardwarePins::CardOK, ok);
}

void SDCardRWController::setupLedBlinkTimer() {
    // Configura Timer2 modo normal, prescaler 1024
    TCCR2A = 0;
    TCCR2B = 0;
    TCNT2 = 0;

    // (16MHz / 1024) / 256 = ~61 Hz overflow
    TCCR2B |= (1 << CS22) | (1 << CS21) | (1 << CS20);
    TIMSK2 |= (1 << TOIE2);  // habilita interrupção de overflow
}

// TODO: migrar Timer2 ISR para Core/Interrupts.cpp quando houver múltiplos serviços com
// interrupções.
ISR(TIMER2_OVF_vect) {
    static uint8_t counter = 0;
    counter++;

    if (counter >= 3) {  // ~12 Hz / 2 = 6 Hz de piscar
        counter = 0;

        // Desativa automaticamente quando chega ao tempo limite
        if (blinkStopTime && millis() > blinkStopTime) {
            ledBlinkEnabled = false;
            blinkStopTime = 0;
            analogWrite(HardwarePins::CardOK, 255);  // acende fixo
        }

        if (ledBlinkEnabled) {
            ledState = !ledState;
            analogWrite(HardwarePins::CardOK, ledState ? 128 : 0);
        }
    }
}

void SDCardRWController::blinkStart() {
    ledBlinkEnabled = true;
    blinkStopTime = 0;  // sem agendamento de parada
}

void SDCardRWController::blinkEnd() {
    // agenda o fim do piscar para daqui 300 ms, sem bloquear
    blinkStopTime = millis() + 300;
}

void SDCardRWController::updateSDCard() {
    Serial.print(F("SDCHK initialized="));
    Serial.print(initialized);
    Serial.print(F(" pin="));
    Serial.println(digitalRead(HardwarePins::MissingSdCard));

    static unsigned long lastToggle = 0;
    static bool blinkState = false;

    // 1️⃣ Verifica se o cartão está presente
    bool cardInserted = (digitalRead(HardwarePins::MissingSdCard) == LOW);

    if (!cardInserted) {
        // Cartão removido
        initialized = false;
        updateLedStatus(true, false, false);  // Vermelho (NoCard)
        return;
    }

    // 2️⃣ Se o cartão foi inserido mas ainda não inicializado, tenta inicializar
    if (!initialized) {
        if (begin()) {
            updateLedStatus(false, false, true);  // Verde fixo (OK)
        } else {
            updateLedStatus(false, true, false);  // Amarelo (falha)
        }
        return;
    }
}

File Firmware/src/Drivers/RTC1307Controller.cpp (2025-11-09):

/**
 * * @file RTC1307Controller.cpp
 *
 * @brief Controlador do módulo RTC DS1307
 *
 * @details
 * Implementa a interface ISensor, fornecendo data e hora formatadas
 * e integração direta com o SystemMediator e DeviceManager.
 * Compatível com SensorData e comandos GET/SET DATE.
 *
 * @author
 *   Fabrício Michel Denes (FMD)
 * @date
 *   2025
 *
 * @copyright
 *   © 2025 Fabrício Michel Denes. Todos os direitos reservados.
 *
 * @license
 *   Este código é distribuído sob a licença MIT.
 *   Consulte o arquivo LICENSE ou visite:
 *   https://opensource.org/licenses/MIT
 *
 * @version
 * * v0.2.x  - Em desenvolvimento
 */

#include "Drivers/RTC1307Controller.h"

RTC1307Controller::RTC1307Controller() {}

void RTC1307Controller::begin() {
    if (!rtc.begin()) {
        Serial.println(F("[RTC1307] Erro: módulo não detectado."));
        return;
    }

    if (!rtc.isrunning()) {
        Serial.println(F("[RTC1307] RTC parado, ajustando data padrão."));
        rtc.adjust(DateTime(F(__DATE__), F(__TIME__)));
    } else {
        Serial.println(F("[RTC1307] Inicializado e em execução."));
    }
}

bool RTC1307Controller::isAvailable() const {
    return rtc.isrunning();
}

void RTC1307Controller::printStatus() const {
    if (!rtc.isrunning()) {
        Serial.println(F("[RTC1307] Não está em execução."));
        return;
    }

    DateTime now = rtc.now();
    Serial.print(F("[RTC1307] "));
    Serial.print(now.year());
    Serial.print('/');
    Serial.print(now.month());
    Serial.print('/');
    Serial.print(now.day());
    Serial.print(' ');
    Serial.print(now.hour());
    Serial.print(':');
    Serial.print(now.minute());
    Serial.print(':');
    Serial.println(now.second());
}

void RTC1307Controller::response() {
    if (!rtc.isrunning()) {
        Serial.println(F("⚠️ RTC não disponível."));
        return;
    }

    DateTime now = rtc.now();
    Serial.print(F("📅 "));
    Serial.print(now.year());
    Serial.print('/');
    Serial.print(now.month());
    Serial.print('/');
    Serial.print(now.day());
    Serial.print(F(" ⏰ "));
    Serial.print(now.hour());
    Serial.print(':');
    Serial.print(now.minute());
    Serial.print(':');
    Serial.println(now.second());
}

void RTC1307Controller::getData(SensorData& out) {
    if (!rtc.isrunning()) {
        out.textCount = 0;
        return;
    }

    DateTime now = rtc.now();
    out.text[0] = String(now.year()) + "/" + String(now.month()) + "/" + String(now.day());
    out.text[1] = String(now.hour()) + ":" + String(now.minute()) + ":" + String(now.second());
    out.textCount = 2;
}

void RTC1307Controller::getFormattedDate(char* dateBuf, char* timeBuf) {
    DateTime now = rtc.now();
    sprintf(dateBuf, "%04d/%02d/%02d", now.year(), now.month(), now.day());
    sprintf(timeBuf, "%02d:%02d:%02d", now.hour(), now.minute(), now.second());
}

void RTC1307Controller::setDateTime(const String& datetime) {
    // Formato esperado: "yyyy-mm-dd hh:mm:ss"
    if (datetime.length() < 19) {
        Serial.println(F("❌ Formato inválido para SET DATE"));
        return;
    }

    int year = datetime.substring(0, 4).toInt();
    int month = datetime.substring(5, 7).toInt();
    int day = datetime.substring(8, 10).toInt();
    int hour = datetime.substring(11, 13).toInt();
    int min = datetime.substring(14, 16).toInt();
    int sec = datetime.substring(17, 19).toInt();

    rtc.adjust(DateTime(year, month, day, hour, min, sec));
    Serial.println(F("✅ Data/hora atualizadas com sucesso."));
}

void RTC1307Controller::appendToLogLine(String& line) {
    SensorData data;
    getData(data);

    if (data.textCount >= 2) {
        line += data.text[0] + ';' + data.text[1] + ';';
    } else {
        line += F("----/--/--;--:--:--;");  // placeholders
    }
}

String RTC1307Controller::logLine() {
    SensorData data;
    getData(data);

    if (data.textCount >= 2) {
        return data.text[0] + ';' + data.text[1] + ';';
    } else {
        return F("----/--/--;--:--:--;");  // placeholders
    }
}

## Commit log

2025-11-09 feat(base): Versão inicial com DHT, RTC e ADC nativos do ATmega2560
    [24C32A.kicad_sch, Battery Keeper 2032 PART.STEP, DG142V-3-5.08.STEP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]
2025-11-09 Adiciona README.md para o projeto eletrônico
2025-11-09 Revert "Para correção da mensagem de commit"
    Reverção de commit para correção da mensagem de commit
    "Remove o diretorio Firmware/lib/ erroneamente incluido em .gitignore"
    This reverts commit 67b3b7ca788ff74ad37eca1d53646c23d2f6961b.
2025-11-10 feat(drivers): adiciona suporte ao ADC MCP3008 como sensores individuais
    - Implementa as classes `Mcp3008Driver` e `Mcp3008ChannelSensor`, integradas à interface ISensor.
    - Cada canal do MCP3008 é tratado como um sensor independente (CH0–CH7).
    - Adiciona construtor padrão para permitir inicialização estática de arrays de sensores.
    - Integra os sensores MCP3008 ao DeviceManager, permitindo registro automático e leitura unificada.
    - Atualiza SystemMediator::generateSaveLine() para incluir canais do MCP (17–18) no log serial.
    - Padroniza a coleta e resposta dos sensores ADC nativos e externos (ATmega2560 + MCP3008).
    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
2025-11-11 feat(core): adiciona arquitetura de serviços e integração do SDCard via ISystemService
    - Cria a nova interface ISystemService para gerenciar periféricos de sistema (SDCard, WiFi, etc.)
    - Refatora o SDCardRWController para herdar de ISystemService e retornar status de gravação (SD=OK / SD=ERR)
    - Adiciona suporte a registro e recuperação de serviços no DeviceManager (services[])
    - Atualiza SystemMediator::generateSaveLine() para incluir o resultado da escrita no SDCard
    - Mantém compatibilidade total com a arquitetura baseada em ISensor e SystemMediator
    - Prepara a base para integração futura de novos serviços (WiFi, NTP, Logger)
    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
2025-11-11 feat(sdcard): adiciona controle completo de LED e verificação dinâmica de inserção/remoção do cartão
    - Implementa controle de presença e reinicialização automática do cartão SD
    - Adiciona lógica não bloqueante de piscar LED verde via Timer2 (6 Hz, 50% duty)
    - Atualiza SDCardRWController::updateSDCard() para executar continuamente, mesmo sem cartão inserido
    - Implementa controle visual completo:
    🔴 Vermelho → cartão ausente
    🟡 Amarelo → falha de leitura/gravação
    🟢 Verde fixo → cartão pronto
    🟢 Verde piscando → operação de escrita ativa
    - Remove delays bloqueantes de blinkEnd(), substituídos por timer de software (millis)
    - Garante que falhas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
    [DeviceManager.cpp, HardwarePins.h, SDCardRWController.cpp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]
2025-11-13 feat(gui): primeira versão funcional do TerraMoistLogger
    Esta é a primeira versão totalmente funcional da interface gráfica
    do TerraMoistLogger, projetada para monitorar múltiplos dispositivos
    TerraMoistSense (4 unidades / 72 sensores capacitivos).
    Principais funcionalidades implementadas:
    - Leitura serial em tempo real via QSerialPort
    - Detecção automática de conexão/desconexão de dispositivos
    - Console estruturado em Qt (QPlainTextEdit)
    - Organização completa do código-fonte em include/, src/ e ui/
    - Interface compatível com Qt 5.5 (32-bit) para suportar sistemas antigos
    Próximos passos em desenvolvimento:
    - Suporte a comunicação WiFi via ESP-01
    - Redesign da UX/UI basea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
    [main.cpp]
